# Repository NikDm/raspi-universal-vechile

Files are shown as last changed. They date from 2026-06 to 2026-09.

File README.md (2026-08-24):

# RasPi Universal Vehicle

A Raspberry Pi Zero 2 W-powered vehicle with dual motor control and live camera
feed, controlled from a PC browser or the Windows desktop application.

> [!WARNING]
> The Windows application uses Electron 22 to retain Windows 7 compatibility.
> Electron 22 and its embedded Chromium version are end-of-life and receive no
> security fixes. The Pi protocol is also unencrypted and unauthenticated. Use
> this controller only with a vehicle on a trusted local network; it is not safe
> to expose to the internet.

## Hardware

### Bill of Materials

| Component | Recommended | Est. Price |
|---|---|---|
| SBC | Raspberry Pi Zero 2 W | ~$20 |
| Motor Driver | TB6612FNG breakout | ~$5 |
| Camera | RPi Camera Module v3 Wide | ~$35 |
| Camera cable | Pi Zero camera ribbon | ~$3 |
| Motors | 2x TT/BO gear motors (3-6V) | ~$5 |
| Chassis | 2WD robot car kit | ~$12 |
| Motor power | 4x AA NiMH or 2S LiPo | ~$10 |
| Pi power | 5V/3A USB power bank | ~$10 |
| GPIO header | Hammer header for Zero | ~$2 |

### GPIO Wiring (TB6612FNG)

```
TB6612FNG Pin    →  Pi Zero 2 W Pin
───────────────────────────────────
VMOT (motor +)   →  Battery positive (4xAA or 2S LiPo)
GND (motor)      →  Battery negative
VCC (logic)      →  3V3 (pin 1)
GND (logic)      →  GND (pin 6)
STBY             →  3V3 (pin 1) — enable
PWMA (left PWM)  →  GPIO 17 (pin 11)
AIN1 (left fwd)  →  GPIO 18 (pin 12)
AIN2 (left rev)  →  GPIO 27 (pin 13)
PWMB (right PWM) →  GPIO 22 (pin 15)
BIN1 (right fwd) →  GPIO 23 (pin 16)
BIN2 (right rev) →  GPIO 24 (pin 18)
AO1 / AO2        →  Left motor
BO1 / BO2        →  Right motor
```

Note: Default GPIO pins can be changed in `pi/motor_controller.py`.

For the complete motor, power, camera, and light diagram, see
[Complete hardware wiring](docs/WIRING.md).

## Pi Setup

### 1. Install Raspberry Pi OS

1. Flash Raspberry Pi OS Bookworm (64-bit) to an SD card using [Raspberry Pi Imager](https://www.raspberrypi.com/software/)
2. In the imager, configure:
   - Hostname: `vehicle`
   - Enable SSH with password authentication
   - Set WiFi SSID/password
   - Set a user password for `user: pi, pwd: pi`

### 2. Enable Camera and SPI

On Raspberry Pi OS Bookworm the CSI camera is auto-detected by `libcamera` — there is no longer a Camera entry in `raspi-config`, and the legacy GPU memory split is no longer used. Verify the camera is visible:

```bash
rpicam-hello --list-cameras
```

You should see your sensor listed (e.g. `ov5647`, `imx219`, `imx708`). If nothing is listed, edit `/boot/firmware/config.txt` and add under `[all]`:

```
dtoverlay=ov5647   # or imx219 / imx477 / imx708 to match your module
```

Then enable SPI (needed for some motor HATs):

```bash
sudo raspi-config
```

- **Interface Options → SPI** → Enable SPI

Reboot: `sudo reboot`

### 3. Install Dependencies

```bash
ssh pi@vehicle.local
sudo apt update && sudo apt upgrade -y
sudo apt install -y python3-lgpio python3-gpiozero python3-picamera2 python3-websockets
```

`gpiozero` uses the `lgpio` backend by default on Raspberry Pi OS Bookworm, which provides hardware-timed PWM on the TB6612FNG enable pins without any extra daemon.

### 4. Deploy the Server Code

On your PC:

```bash
cd raspi-universal-vehicle
./deploy.sh vehicle.local
```

Or manually:

```bash
scp -r pi pi@vehicle.local:/home/pi/vehicle
```

### 5. Configure and Start at Boot

SSH into the Pi:

```bash
ssh pi@vehicle.local
cd ~/vehicle
```

Find the Pi's IP address:
```bash
hostname -I
```

Install the included systemd service and start it immediately:
```bash
sudo install -m 0644 vehicle.service /etc/systemd/system/vehicle.service
sudo systemctl daemon-reload
sudo systemctl enable --now vehicle.service
```

The service now starts automatically on every boot. Confirm that it is running:

```bash
systemctl status vehicle.service
```

Press `q` to exit the status view. To follow the server logs:

```bash
journalctl -u vehicle.service -f
```

After deploying later code changes, restart the running server:

```bash
sudo systemctl restart vehicle.service
```

If `vehicle.service` itself changes, repeat the `install` and `daemon-reload`
commands before restarting. To disable automatic startup and stop the server:

```bash
sudo systemctl disable --now vehicle.service
```

For a root-only DietPi installation deployed to `/opt/vehicle`, install the
DietPi-specific unit instead:

```bash
install -m 0644 vehicle-dietpi.service /etc/systemd/system/vehicle.service
systemctl daemon-reload
systemctl enable --now vehicle.service
```

## PC Setup

### Windows desktop application

Separate installers support 32-bit and x64 editions of Windows 7 SP1, Windows
8.1, and Windows 10. Use the x64 installer on Windows 11. Windows 7 must have
current SHA-2 code-signing and TLS-related operating-system updates installed.
Node.js and development tools are not required to run the installed application.

1. Download the matching installer from the GitHub Release: choose the `ia32`
   filename for 32-bit Windows or `x64` for 64-bit Windows.
2. Run the installer. It installs for the current user without administrator
   privileges and creates Desktop and Start Menu shortcuts.
3. Start **RasPi Vehicle Control**, enter the Pi hostname or IP address, and use
   the controls as described below. The address is saved between launches.

The installer is currently unsigned, so Windows may show an unknown-publisher
prompt or SmartScreen warning. Verify that the file came from this repository's
GitHub Release before choosing to run it. If Windows 7 cannot access GitHub
because its browser or TLS support is too old, download the installer on a
supported computer and transfer it using removable media or another trusted
local method.

To uninstall, open **Control Panel → Programs and Features**, select
**RasPi Vehicle Control**, and choose **Uninstall**. Uninstalling leaves the
saved Pi address in the current user's application data so a reinstall retains
it.

### Browser development setup

### Install Node.js

Requires Node.js 18+.

```bash
cd raspi-universal-vehicle/ui
npm install
```

### Run the UI

```bash
npm run dev
```

Open http://localhost:3000 in your browser.

Enter the Pi's IP address in the input field. The UI will auto-connect and remember the last value in local storage.

### Install the offline web app on Android

The production UI is an installable PWA. Its application shell is cached, so
after the first successful installation it can launch without access to the
hosting network. The live controls and video still require a LAN connection to
the Pi.

1. Build and publish `ui/dist/` on an HTTPS website. A raw IP address served
   over HTTP is not sufficient for reliable PWA installation.
2. Open that HTTPS URL in Chrome on the Android phone while it has internet
   access.
3. Wait for the first page load to complete, then choose **Install app** from
   Chrome's menu.
4. Launch the installed app once while still online so the initial cache and
   any service-worker update can finish.
5. Connect the phone to the vehicle Ethernet network and open the installed
   app. The default Pi address is `192.168.50.1`; it can be changed from
   **Info** and is saved between launches.

Android may prefer an internet-capable WiFi or cellular network over isolated
Ethernet. Select Ethernet as the preferred network or temporarily disable the
other transports. The HTTPS-hosted PWA also needs the browser's local-network
permission to open the Pi's unencrypted `ws://` control socket and HTTP MJPEG
stream. Browser support for HTTPS-to-local-HTTP access varies; use the regular
HTTP UI on the Pi or a native Android wrapper if the installed PWA cannot reach
those endpoints.

The offline cache contains only the UI application shell. It intentionally does
not cache the camera stream or vehicle commands.

### Build or run the desktop application locally

Use Node.js 18 or newer for local development. Release automation uses Node.js
22. From the `ui` directory:

```bash
npm ci
npm run desktop:run
```

`desktop:run` builds the UI and launches Electron. It does not start the Pi
server or a Vite development server.

Create both unsigned Windows installers on Windows with:

```powershell
npm ci
npm run build
npm run desktop:dist
```

The installers are written to `ui/release/` as
`RasPi-Vehicle-Control-Setup-<version>-win7-compatible-ia32.exe` and
`RasPi-Vehicle-Control-Setup-<version>-win7-compatible-x64.exe`. Windows 7 is
a runtime target, not a supported build environment.

### Publish a Windows release

1. Set `ui/package.json` to the release version and commit the package and
   lock files.
2. Create and push a matching `v<version>` tag. For version `1.0.0`:

   ```bash
   git tag v1.0.0
   git push origin v1.0.0
   ```

The Windows workflow checks that the tag and package version match, runs
`npm ci` and the strict UI build on Windows, builds the unsigned installer,
and attaches it to a versioned GitHub Release.

## Usage

### Keyboard Controls

| Key | Action |
|---|---|
| W / Arrow Up | Forward |
| S / Arrow Down | Reverse |
| A / Arrow Left | Turn left |
| D / Arrow Right | Turn right |
| Space | Brake (stop) |

The UI ignores driving keys while you are typing in the Pi IP field. Switching tabs or moving focus away from the browser leaves the current keyboard motor levels unchanged; press Space to stop.

Use the **Refresh** button in the header to reload the UI, equivalent to
pressing Ctrl+R in a browser.

On a touchscreen, tap the semi-transparent **↑**, **STOP**, and **↓** buttons
over the video feed to change throttle or stop immediately.

The camera feed is centered and preserves its native 4:3 aspect ratio.

Use the **Info** button to edit the Pi IP address and view control instructions.
Opening the dialog stops the vehicle and temporarily disables driving controls.

### Gamepad Controls

Connect any USB or Bluetooth gamepad (Xbox, PlayStation, etc.). The left stick controls steering and throttle with a deadzone of 0.1.

## Architecture

```
┌────────────────────────────┐
│ PC Browser / Windows App   │
│  React + TypeScript UI     │
│  - Video feed (MJPEG)      │
│  - WebSocket controls       │
│  - Gamepad / keyboard       │
└────────────┬───────────────┘
             │ WiFi (LAN)
             │
┌────────────▼───────────────┐
│    Raspberry Pi Zero 2 W    │
│                             │
│  Python asyncio server      │
│  ├─ :8080 WebSocket         │
│  └─ :8081 MJPEG HTTP        │
│                             │
│  gpiozero MotorController   │
│  picamera2 CameraStream     │
└─────────────────────────────┘
```

## Project Structure

```
raspi-universal-vechile/
├── pi/
│   ├── server.py          # Main entry point
│   ├── motor_controller.py # gpiozero wrapper
│   ├── camera.py          # picamera2 MJPEG
│   ├── vehicle.service    # systemd boot service
│   ├── vehicle-dietpi.service # root-only DietPi systemd service
│   └── requirements.txt   # Python deps
├── ui/
│   ├── desktop/
│   │   ├── main.cjs       # Hardened Electron main process
│   │   └── icon.png       # Window, executable, and shortcut icon
│   ├── src/
│   │   ├── App.tsx        # Main app
│   │   ├── types.ts       # Shared types
│   │   ├── components/
│   │   │   ├── VideoFeed.tsx
│   │   │   ├── Controls.tsx
│   │   │   └── ConnectionIndicator.tsx
│   │   └── hooks/
│   │       ├── useWebSocket.ts
│   │       └── useGamepad.ts
│   ├── public/
│   │   └── icons/          # Android/PWA installation icons
│   ├── package.json
│   ├── vite.config.ts
│   └── tsconfig.json
├── .github/workflows/
│   └── windows-release.yml # Tagged Windows release build
├── deploy.sh              # Deploy script
├── TODO.md                 # Proposed work and completion tracking
└── README.md
```

## Troubleshooting

### Windows application does not start

- Confirm the installer architecture matches Windows: `ia32` for 32-bit or
  `x64` for 64-bit. Use x64 on Windows 11.
- On Windows 7, install SP1 and current SHA-2 and TLS-related operating-system
  updates, then reboot.
- Re-download the installer from the matching GitHub Release if Windows reports
  that it is damaged. An unknown-publisher warning is expected because releases
  are not yet code-signed.
- The application should still open when the Pi or camera is unavailable. Check
  that the Pi is powered on, both devices are on the same trusted LAN, and ports
  8080 and 8081 are not blocked if controls or video remain disconnected.
- After a connection interruption, the controls and camera feed reconnect
  automatically. The camera feed retries every three seconds while unavailable.

Electron 22 is deliberately pinned for Windows 7 support and is end-of-life.
Do not browse arbitrary sites in the application or expose the Pi services to
the internet.

### Camera not detected
```bash
# Check camera is connected (Bookworm / libcamera)
rpicam-hello --list-cameras
# Should list your sensor, e.g. "ov5647" or "imx708"
```

Note: `vcgencmd get_camera` is the legacy check and will report `detected=0` on Bookworm even when the camera works correctly — use `rpicam-hello --list-cameras` instead.

If no camera is detected when the server starts, it logs a warning and continues
serving motor and light controls. The video feed remains unavailable until a
camera is connected and the server is restarted.

If the camera is not listed, add `dtoverlay=<sensor>` under `[all]` in `/boot/firmware/config.txt` (e.g. `dtoverlay=ov5647` for OV5647-based modules like the SainSmart 5MP fisheye) and reboot.

### Motors not responding

Verify:
- `STBY` on the TB6612FNG is tied high to `3V3`
- The Pi ground and motor battery ground are connected together
- The default pins in `pi/motor_controller.py` match your wiring: left `17/18/27`, right `22/23/24`
- The user running `server.py` is in the `gpio` group (`groups | grep gpio`); the default `pi` user already is

### High video latency
- Lower the resolution in `pi/server.py` (`width`, `height`)
- Reduce `framerate` to 20
- Move the Pi closer to the WiFi router

The defaults (`1296x972 @ 30fps`) are tuned for the OV5647 sensor (e.g. SainSmart 5MP fisheye), which supports up to `1296x972 @ 46fps` natively. Drop to `640x480` and/or `framerate=20` in `pi/server.py` if you see lag over WiFi.

### "No route to host" or intermittent connection drops

Pi Zero 2 W defaults to aggressive WiFi power save, which causes the Pi to become unreachable seconds after going idle. Symptoms: the server logs show a brief client connection, then the browser reports `ERR_ADDRESS_UNREACHABLE` and `nc` reports "No route to host" from the PC.

Disable WiFi power save permanently on the Pi:

```bash
# One-shot (effective until reboot)
sudo iw dev wlan0 set power_save off

# Persistent across reboots (NetworkManager, default on Bookworm)
ACTIVE=$(nmcli -t -f NAME connection show --active | head -n1)
sudo nmcli connection modify "$ACTIVE" wifi.powersave 2
sudo nmcli connection up "$ACTIVE"

# Verify
iw dev wlan0 get power_save   # should print "Power save: off"
```

Also worth checking:
- Use `vehicle.local` in the UI instead of the raw IP to avoid stale DHCP leases.
- If `ping` to the Pi fails from the PC, confirm both are on the same SSID and that the router does not have AP/client isolation enabled.

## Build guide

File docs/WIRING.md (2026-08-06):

# Complete hardware wiring

## Native Fritzing project

[Open or download the editable Fritzing project](raspi-vehicle.fzz)

Breadboard view exported by Fritzing

The native sketch uses Fritzing core parts for the Pi Zero, TB6612FNG, two DC
motors, and motor battery. The light is intentionally omitted. The Pi core part
does not expose CSI or USB power as electrical connectors, so connect the camera
ribbon and regulated 5 V USB supply physically as described below. The bundled
TB6612 artwork differs from the compact red board, but its logical AIN/BIN pins
correspond to the red module labels AI/BI.

Each project net is routed through two editable orthogonal bendpoints, with
separate lanes for power, ground, control signals, and motor outputs.

## Fritzing-style diagram (light omitted)

[Open the editable SVG diagram](raspi-vehicle-fritzing.svg)

Fritzing-style Raspberry Pi vehicle wiring without light

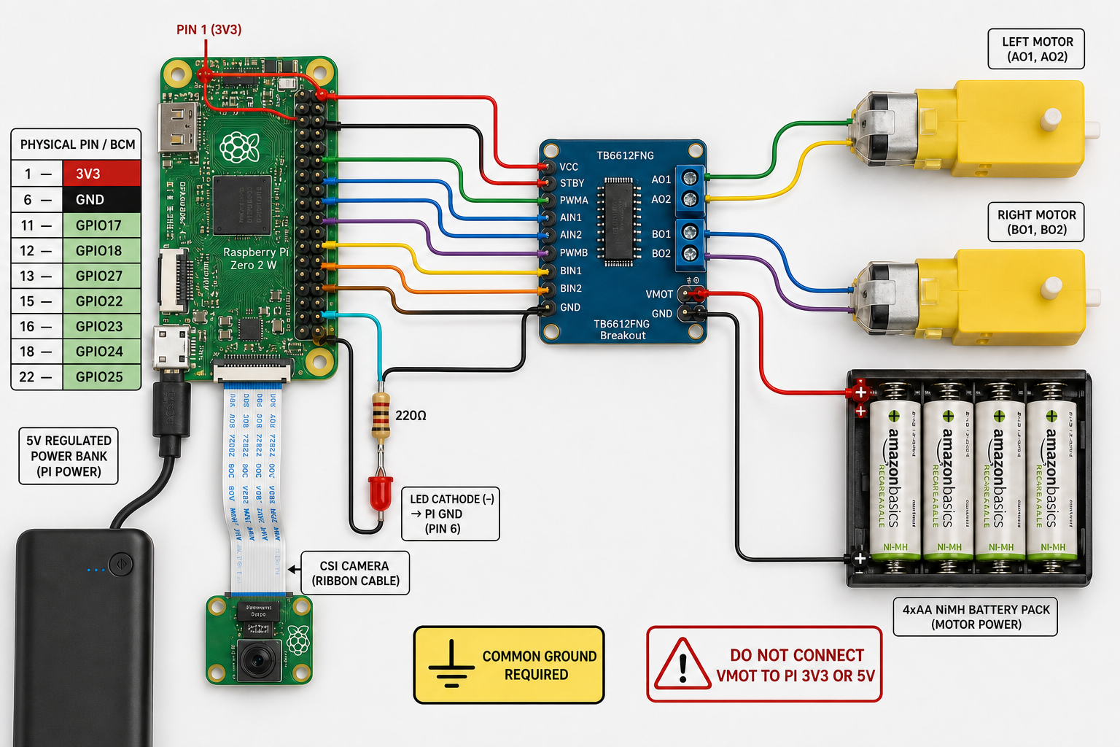
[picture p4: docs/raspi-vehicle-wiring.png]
Raspberry Pi Zero 2 W vehicle hardware wiring


This covers the Raspberry Pi Zero 2 W, TB6612FNG driver, two DC motors, CSI
camera, GPIO light, and both power supplies.

> **Disconnect both power sources before changing wiring.** Never connect motor
> battery positive (`VMOT`) to a Pi 3V3 or 5V pin.

## Connection schematic

```mermaid
flowchart LR
  subgraph PI["Raspberry Pi Zero 2 W"]
    P3V3["3V3 - physical pin 1"]
    PGND["GND - physical pin 6"]
    G17["GPIO17 - pin 11"]
    G18["GPIO18 - pin 12"]
    G27["GPIO27 - pin 13"]
    G22["GPIO22 - pin 15"]
    G23["GPIO23 - pin 16"]
    G24["GPIO24 - pin 18"]
    G25["GPIO25 - pin 22"]
    CSI["CSI camera connector"]
    USB["5 V USB power input"]
  end
  subgraph TB["TB6612FNG motor driver"]
    VCC[VCC]
    STBY[STBY]
    DGND[GND]
    PWMA[PWMA]
    AIN1[AIN1]
    AIN2[AIN2]
    PWMB[PWMB]
    BIN1[BIN1]
    BIN2[BIN2]
    VMOT["VM / VMOT"]
    AO["AO1 + AO2"]
    BO["BO1 + BO2"]
  end
  P3V3 -->|"3.3 V logic"| VCC
  P3V3 -->|"driver enabled"| STBY
  PGND ---|"common ground"| DGND
  G17 -->|"left PWM"| PWMA
  G18 -->|"left forward"| AIN1
  G27 -->|"left reverse"| AIN2
  G22 -->|"right PWM"| PWMB
  G23 -->|"right forward"| BIN1
  G24 -->|"right reverse"| BIN2
  AO --- LM["Left DC motor"]
  BO --- RM["Right DC motor"]
  BATP["Motor battery +"] --> VMOT
  BATN["Motor battery -"] --- DGND
  G25 --> R["220 ohm resistor"]
  R --> LED["LED anode +"]
  LED -->|"cathode -"| PGND
  CAM["Raspberry Pi camera"] ---|"Pi Zero CSI ribbon"| CSI
  PSU["Regulated 5 V / 3 A supply"] --> USB
```

Motor battery negative, driver ground, and Pi ground **must share a common
ground**. Keep positive supplies separate: regulated 5 V powers the Pi through
USB, while the motor battery powers only `VMOT`.

## Exact Pi pin connections

| Pi signal | Physical pin | Connect to | Purpose |
|---|---:|---|---|
| 3V3 | 1 | TB6612FNG `VCC` | Driver logic supply |
| 3V3 | 1 | TB6612FNG `STBY` | Enable driver |
| GND | 6 | TB6612FNG `GND` | Common ground |
| GPIO17 | 11 | TB6612FNG `PWMA` | Left speed/PWM |
| GPIO18 | 12 | TB6612FNG `AIN1` | Left direction 1 |
| GPIO27 | 13 | TB6612FNG `AIN2` | Left direction 2 |
| GPIO22 | 15 | TB6612FNG `PWMB` | Right speed/PWM |
| GPIO23 | 16 | TB6612FNG `BIN1` | Right direction 1 |
| GPIO24 | 18 | TB6612FNG `BIN2` | Right direction 2 |
| GPIO25 | 22 | 220 ohm resistor, then LED anode | Light output |
| GND | Any free GND | LED cathode | Light return |
| CSI connector | - | Camera ribbon | Camera data and power |
| USB power input | - | Regulated 5 V supply | Pi power |

## Motor and power connections

| Source | Connect to | Notes |
|---|---|---|
| Motor battery positive | `VM`, `VMOT`, or `VMCC` | Label varies by breakout |
| Motor battery negative | Driver GND and Pi GND | Required common reference |
| `AO1`, `AO2` | Left motor terminals | Swap pair if forward is reversed |
| `BO1`, `BO2` | Right motor terminals | Swap pair if forward is reversed |
| Regulated 5 V supply | Pi USB power input | Never connect to `VMOT` |

Use a supply compatible with the motors and driver. The current recommendation
is 4xAA NiMH. Before using a 2S LiPo, confirm the motors tolerate its fully
charged voltage and use suitable LiPo protection. Many 3-6 V TT motors should
not receive full 2S voltage directly.

## Camera and LED

Use the narrow Pi Zero CSI cable. Release each latch before inserting the cable,
keep it square, and close both latches evenly. Follow the markings on the exact
Pi and camera boards because ribbon orientation can vary.

```text
GPIO25 (physical pin 22) -> 220 ohm resistor -> LED anode (+)
LED cathode (-)          -> Pi GND
```

For a typical through-hole LED, the long leg is the anode and the flat body
edge marks the cathode. Do not drive a high-power lamp or LED strip directly
from GPIO25; use a suitable transistor or MOSFET driver.

## Header orientation

Physical pin numbers differ from BCM GPIO numbers. Python uses BCM names such
as `GPIO17`. With the Pi Zero USB ports at the bottom and header at the top,
physical pin 1 is top-left. Confirm it from the square pad or `3V3` marking.

## Before applying power

- Confirm `VMOT` does not connect to any Pi power pin.
- Check continuity between Pi GND, driver GND, and motor battery negative.
- Check for shorts between 3V3, 5V, `VMOT`, and GND.
- Confirm `VCC` and `STBY` connect to 3V3.
- Confirm the LED has a series resistor and correct polarity.
- Raise the wheels off the ground for the first motor test.
- Power the Pi first; connect motor power only when ready to test.
- Be ready to disconnect motor power immediately.

The code defaults are authoritative in `pi/motor_controller.py` and
`pi/light_controller.py`. Update this document when those assignments change.

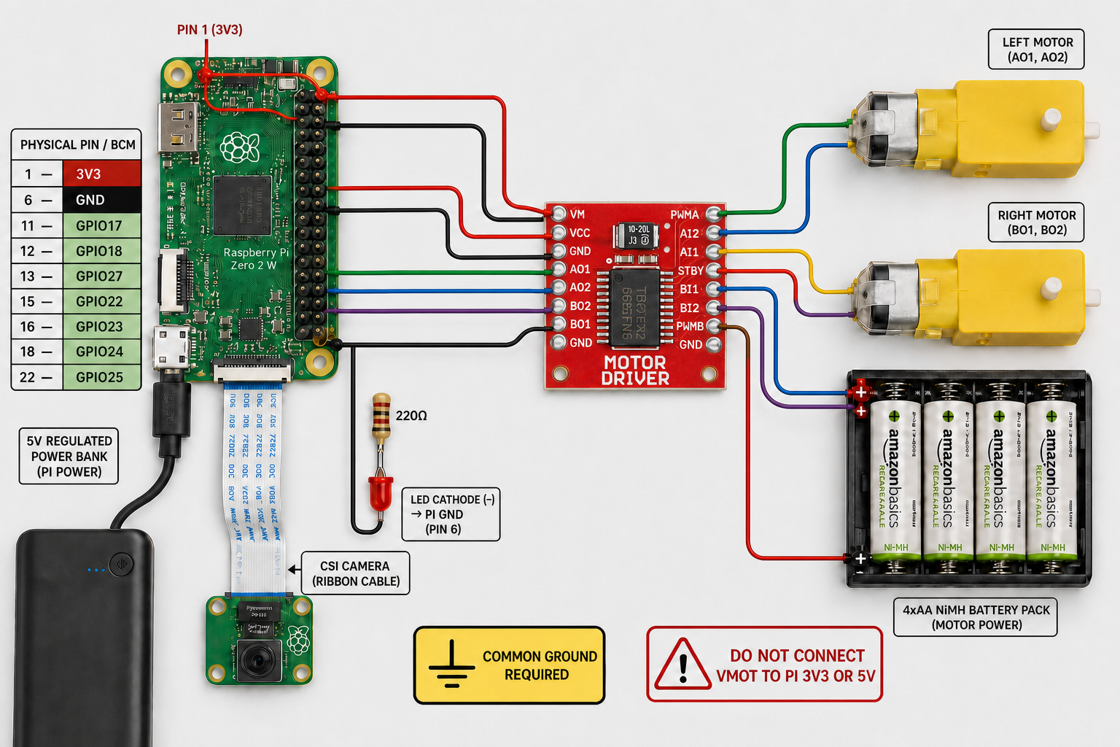
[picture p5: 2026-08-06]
docs/raspi-vehicle-wiring-compact-driver-draft.png

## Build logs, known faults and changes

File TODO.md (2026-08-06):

# Project TODO

This list tracks proposed work for the Raspberry Pi vehicle. Safety-critical and
reliability work should take priority over convenience features. Items that need
vehicle hardware must not be marked complete based only on desktop testing.

## Safety and control

- [ ] Reject non-finite, malformed, or out-of-range command values before they
  reach the motor controller; retain motor-side clamping as a final safeguard.
- [ ] Document and test emergency-stop behavior for browser focus loss, controller
  disconnect, WebSocket loss, last-client disconnect, and server shutdown.

## Reliability and observability

- [ ] Add clear connection and command-error feedback to the browser UI.
- [ ] Keep the light and motor gauges synchronized with status messages returned
  by the Pi rather than relying only on locally requested state.
- [ ] Add a lightweight health/status endpoint suitable for troubleshooting the
  WebSocket server, camera stream, and connected-client count.

## Testing and developer workflow

- [ ] Add hardware-independent unit tests for command parsing, numeric validation,
  clamping, and disconnect-stop behavior using fake motor and light controllers.
- [ ] Add UI tests for keyboard input suppression while typing, focus-loss stop,
  gamepad disconnect stop, and command generation.
- [ ] Add documented `test` and `lint` package scripts when those tools are added.
- [ ] Add a CI workflow that runs the UI build, Python syntax checks, and all
  hardware-independent tests without importing GPIO-backed modules.
- [ ] Create a short manual hardware test checklist for connect, move, stop,
  disconnect, light, camera, and clean shutdown behavior.
- [x] Create a Windows executable that starts the UI with one click, and document
  how to build, distribute, run, and troubleshoot it.
  
## Documentation and setup

- [ ] Reconcile README examples with current defaults, including camera settings,
  the light controller, project tree, and Raspberry Pi username assumptions.
- [ ] Document every browser-to-Pi command and Pi-to-browser status message with
  example JSON and validation rules.
- [ ] Document configuration options for GPIO pins, ports, camera quality, frame
  size, frame rate, and motor tuning without requiring source edits.
- [ ] Provide a checked systemd service file and installation instructions that
  preserve clean shutdown and automatic motor stopping.
- [ ] Add a first-run verification path covering power isolation, common ground,
  camera detection, GPIO permissions, networking, and wheels-off-ground testing.

## Proposed enhancements

These are ideas, not existing or committed functionality.

- [ ] Consider configurable steering sensitivity, deadzone, and maximum speed.
- [ ] Consider recording diagnostic events without writing excessively to the
  Raspberry Pi SD card.

## Completion checklist

For each completed item:

- [ ] Keep `ui/src/types.ts` and `pi/server.py` synchronized for protocol changes.
- [ ] Update `README.md` and wiring documentation when behavior or setup changes.
- [ ] Run `cd ui && npm run build` for UI changes.
- [ ] Run `python3 -m compileall -q pi` for Python changes.
- [ ] State which hardware checks were performed and which remain unverified.

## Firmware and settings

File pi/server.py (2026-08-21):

import asyncio
import json
import logging
import signal
from http.server import BaseHTTPRequestHandler, ThreadingHTTPServer
import threading

from websockets.asyncio.server import serve
from websockets.exceptions import ConnectionClosed

from motor_controller import MotorController
from light_controller import LightController
from camera import CameraStream

logging.basicConfig(
    level=logging.INFO,
    format="%(asctime)s [%(levelname)s] %(name)s: %(message)s",
)
logger = logging.getLogger(__name__)

WS_HOST = "0.0.0.0"
WS_PORT = 8080
MJPEG_HOST = "0.0.0.0"
MJPEG_PORT = 8081

motor = MotorController()
light = LightController(pin=25)
camera = CameraStream(width=960, height=720, framerate=15, quality=70)
clients = 0
mjpeg_server: ThreadingHTTPServer | None = None


class MJPEGHandler(BaseHTTPRequestHandler):
    def do_GET(self):
        if self.path == "/video":
            self.send_response(200)
            self.send_header("Content-Type", "multipart/x-mixed-replace; boundary=frame")
            self.send_header("Cache-Control", "no-cache")
            self.end_headers()

            frame_id = -1
            try:
                while camera.is_streaming:
                    frame_id, frame = camera.get_frame(frame_id)
                    if frame:
                        self.wfile.write(b"--frame\r\n")
                        self.wfile.write(b"Content-Type: image/jpeg\r\n")
                        self.wfile.write(f"Content-Length: {len(frame)}\r\n\r\n".encode())
                        self.wfile.write(frame)
                        self.wfile.write(b"\r\n")
                    else:
                        break
            except (BrokenPipeError, ConnectionResetError):
                pass
        else:
            self.send_response(404)
            self.end_headers()

    def log_message(self, format, *args):
        pass


async def websocket_handler(ws):
    global clients

    clients += 1
    logger.info(f"Client connected: {ws.remote_address}")
    try:
        async for msg in ws:
            logger.info(f"Received: {msg}")
            try:
                data = json.loads(msg)
                cmd_type = data.get("type")
                if cmd_type == "move":
                    left = float(data.get("left", 0))
                    right = float(data.get("right", 0))
                    motor.move(left, right)
                elif cmd_type == "stop":
                    motor.stop()
                elif cmd_type == "light":
                    if "on" in data:
                        light.set(bool(data.get("on")))
                    else:
                        light.toggle()
                else:
                    logger.warning(f"Unknown command type: {cmd_type}")
                await ws.send(
                    json.dumps(
                        {
                            "type": "status",
                            "left": motor.speeds[0],
                            "right": motor.speeds[1],
                            "light": light.is_on,
                        }
                    )
                )
            except json.JSONDecodeError:
                logger.warning(f"Invalid JSON: {msg}")
            except Exception as exc:
                logger.error(f"Command error: {exc}")
    except ConnectionClosed:
        pass
    finally:
        clients = max(0, clients - 1)
        if clients == 0:
            motor.stop()
        logger.info(f"Client disconnected: {ws.remote_address}")


def run_mjpeg_server(server: ThreadingHTTPServer):
    logger.info(f"MJPEG server started on {MJPEG_HOST}:{MJPEG_PORT}")
    server.serve_forever(poll_interval=0.5)


async def run_servers():
    stop_event = asyncio.Event()
    loop = asyncio.get_running_loop()

    for sig in (signal.SIGINT, signal.SIGTERM):
        loop.add_signal_handler(sig, stop_event.set)

    global mjpeg_server
    try:
        camera.start()
    except RuntimeError as exc:
        logger.warning(f"Camera unavailable; continuing without video: {exc}")
    mjpeg_server = ThreadingHTTPServer((MJPEG_HOST, MJPEG_PORT), MJPEGHandler)
    mjpeg_thread = threading.Thread(target=run_mjpeg_server, args=(mjpeg_server,), daemon=True)
    mjpeg_thread.start()

    async with serve(websocket_handler, WS_HOST, WS_PORT, ping_interval=20, ping_timeout=20):
        logger.info(f"WebSocket server started on {WS_HOST}:{WS_PORT}")
        await stop_event.wait()

    logger.info("Shutdown signal received")
    mjpeg_server.shutdown()
    mjpeg_server.server_close()
    camera.stop()
    motor.close()
    light.close()


def main():
    logger.info("Starting RasPi Universal Vehicle server...")
    asyncio.run(run_servers())
    logger.info("Server stopped")


if __name__ == "__main__":
    main()

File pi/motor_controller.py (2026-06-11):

import logging
import threading
import time
from typing import Tuple

import gpiozero

logging.basicConfig(level=logging.INFO)
logger = logging.getLogger(__name__)


class MotorController:
    def __init__(
        self,
        left_enable: int = 17,
        left_forward: int = 18,
        left_backward: int = 27,
        right_enable: int = 22,
        right_forward: int = 23,
        right_backward: int = 24,
        ramp_time: float = 0.15,
        ramp_steps: int = 15,
    ):
        """
        ramp_time:  total seconds to ramp from current speed to a higher target.
        ramp_steps: number of intermediate steps during the ramp. More steps =
                    smoother, but more PWM writes. ramp_time / ramp_steps is the
                    delay between steps.

        Soft-start only applies when the magnitude of a motor's speed is
        increasing (spin-up), where the current inrush spike happens. Slowing
        down or stopping is applied immediately for responsiveness and safety.
        """
        self.left_motor = gpiozero.Motor(
            forward=left_forward,
            backward=left_backward,
            enable=left_enable,
            pwm=True,
        )
        self.right_motor = gpiozero.Motor(
            forward=right_forward,
            backward=right_backward,
            enable=right_enable,
            pwm=True,
        )
        # _left_speed/_right_speed are the actual PWM values currently applied
        # (which lag during a ramp). _target_* are the most recently commanded
        # values, reported via the `speeds` property.
        self._left_speed = 0.0
        self._right_speed = 0.0
        self._target_left = 0.0
        self._target_right = 0.0

        self.ramp_time = ramp_time
        self.ramp_steps = max(1, ramp_steps)

        # Protects motor writes and the ramp thread lifecycle.
        self._lock = threading.Lock()
        self._ramp_thread: threading.Thread | None = None
        self._cancel_ramp = threading.Event()

        logger.info(
            "MotorController initialized: "
            f"L=({left_enable},{left_forward},{left_backward}), "
            f"R=({right_enable},{right_forward},{right_backward}), "
            f"ramp_time={ramp_time}s, ramp_steps={ramp_steps}"
        )

    @staticmethod
    def _clamp(value: float) -> float:
        return max(-1.0, min(1.0, value))

    def _cancel_active_ramp(self) -> None:
        """Stop any in-progress ramp thread. Caller must not hold _lock."""
        thread = self._ramp_thread
        if thread is not None and thread.is_alive():
            self._cancel_ramp.set()
            thread.join(timeout=self.ramp_time + 0.1)
        self._ramp_thread = None
        self._cancel_ramp.clear()

    def _apply(self, left: float, right: float) -> None:
        """Write speeds to the motors and record them. Holds _lock."""
        with self._lock:
            self._left_speed = left
            self._right_speed = right
            self.left_motor.value = left
            self.right_motor.value = right

    def move(self, left: float, right: float) -> None:
        left = self._clamp(left)
        right = self._clamp(right)
        self._target_left = left
        self._target_right = right

        # Always cancel any running ramp before starting a new command.
        self._cancel_active_ramp()

        start_left = self._left_speed
        start_right = self._right_speed

        # Soft-start only when a motor's magnitude increases (spin-up inrush).
        increasing = abs(left) > abs(start_left) or abs(right) > abs(start_right)

        if not increasing or self.ramp_time <= 0:
            self._apply(left, right)
            return

        self._cancel_ramp.clear()
        self._ramp_thread = threading.Thread(
            target=self._ramp,
            args=(start_left, start_right, left, right),
            daemon=True,
        )
        self._ramp_thread.start()

    def _ramp(self, start_left: float, start_right: float, target_left: float, target_right: float) -> None:
        step_delay = self.ramp_time / self.ramp_steps
        for i in range(1, self.ramp_steps + 1):
            if self._cancel_ramp.is_set():
                return
            t = i / self.ramp_steps
            cur_left = start_left + (target_left - start_left) * t
            cur_right = start_right + (target_right - start_right) * t
            self._apply(cur_left, cur_right)
            if i < self.ramp_steps:
                time.sleep(step_delay)
        # Ensure exact final value (avoids float rounding leaving us short).
        if not self._cancel_ramp.is_set():
            self._apply(target_left, target_right)

    def stop(self) -> None:
        # Stop is immediate: cancel any ramp and cut power.
        self._cancel_active_ramp()
        with self._lock:
            self._left_speed = 0.0
            self._right_speed = 0.0
            self._target_left = 0.0
            self._target_right = 0.0
            self.left_motor.stop()
            self.right_motor.stop()

    def close(self) -> None:
        self.stop()
        with self._lock:
            self.left_motor.close()
            self.right_motor.close()

    @property
    def speeds(self) -> Tuple[float, float]:
        """Most recently commanded target speeds (not the live ramping value)."""
        return (self._target_left, self._target_right)

    @property
    def applied_speeds(self) -> Tuple[float, float]:
        """The PWM values actually applied right now (lags during a ramp)."""
        return (self._left_speed, self._right_speed)

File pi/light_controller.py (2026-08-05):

import logging

import gpiozero

logging.basicConfig(level=logging.INFO)
logger = logging.getLogger(__name__)


class LightController:
    """Simple on/off LED driven directly from a GPIO pin.

    The LED is wired: GPIO -> resistor -> LED anode -> LED cathode -> GND.
    A 220ohm resistor keeps current around 6mA at 3.3V, well within the
    Pi's per-pin limit.
    """

    def __init__(self, pin: int = 25):
        self._led = gpiozero.LED(pin)
        self._on = False
        logger.info(f"LightController initialized on GPIO{pin}")

    def set(self, on: bool) -> None:
        self._on = bool(on)
        if self._on:
            self._led.on()
        else:
            self._led.off()

    def toggle(self) -> bool:
        self.set(not self._on)
        return self._on

    @property
    def is_on(self) -> bool:
        return self._on

    def close(self) -> None:
        self.set(False)
        self._led.close()

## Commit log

2026-06-01 Optimized camera feed, logging ws
2026-06-11 feat: Motor controller
2026-08-06 chore: wiring diagrams
    [raspi-vehicle.fzz]
